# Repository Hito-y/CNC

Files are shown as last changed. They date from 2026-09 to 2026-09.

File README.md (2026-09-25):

# 自作CNC フレーム (PrintNC V4 ベース / 3Dプリンター不要版)

[PrintNC](https://wiki.printnc.info/en/home) V4 の構成 (75x50x3 角パイプ + HGR20 レール + 1610 ボールねじ) をベースに、
**3Dプリント部品を使わず、角パイプ・平板・山形鋼の切断と穴あけだけで作れる**ように簡易化したフレームの
パラメトリック 3D モデル (Python / CadQuery) です。

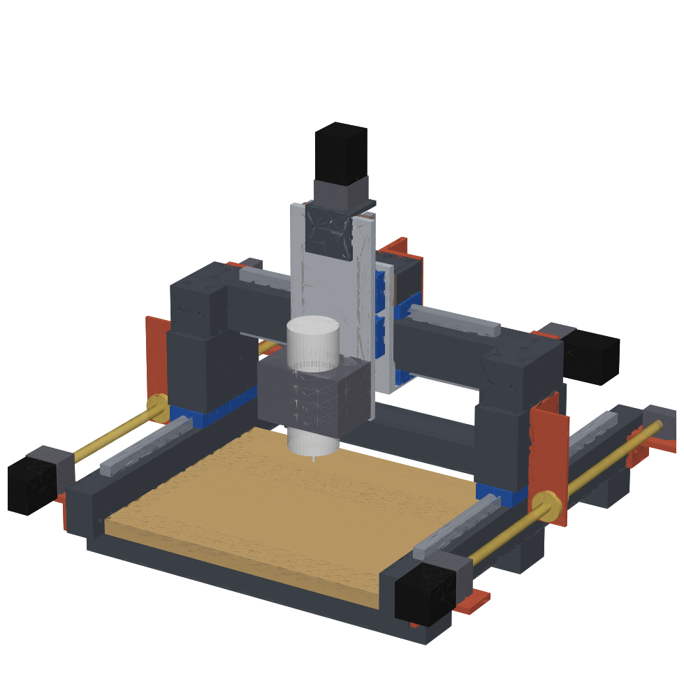
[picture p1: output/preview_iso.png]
preview


## 元モデルについて

- PrintNC V4 の公式 Fusion 360 モデル (V4.0.30 Metalcutter / Woodcutter) は **Discord でのみ配布** されていて、
  この環境からはダウンロードできませんでした ([Files ページ](https://wiki.printnc.info/en/v4/files))。
- 代わりに、公開されている V4 の BOM 生成スクリプト
  [interias/PrintNC-BOM-Generator](https://github.com/interias/PrintNC-BOM-Generator) の部品定義
  (Y Frame / X Frame / Y Roller / Y Roller Brace / X Gantry / X Roller / 1Z Plate / 全ネジ締結 など) を参考に、
  構成を Python で組み直しています。**寸法は V4 公式モデルと一致しません。**
- 公式 `.f3d` を Discord から入手したら、STEP で書き出してこのリポジトリに置けば、寸法の照合と修正ができます。
- PrintNC は CC BY 4.0 です。

## 3Dプリント部品の置き換え

| V4 の部品 | この版での置き換え |
|---|---|
| ローラープレート (15mm 3Dプリント) | 12mm アルミ板 (V4 でも切削版として指定されている厚み) |
| ボールねじナットマウント (印刷/切削) | 山形鋼に Φ29 の穴を開けてナットを直接固定 |
| Z 軸まわりの印刷部品 | 12mm アルミ Z プレート、Z レール下のスペーサー (平鋼 20x10)、HM10-57 取付用の山形鋼 |
| BK/BF/HM の台座 | 平鋼スペーサー / 山形鋼 |
| 印刷ドリルガイド・組立治具 | 自動生成する **穴位置表 (CSV)** と **1:1 型紙 (SVG)**。組立時の直角は対角線を測って出す |
| フレーム接合 | 溶接なし。M8 ボルト + リベットナット、M6 皿ボルトで締結 |

## 公式 .f3d を STEP に変換する (Fusion スクリプト)

`.f3d` は Autodesk Fusion 専用の形式で、Fusion の外では読めない。
[`tools/F3dToStep`](tools/F3dToStep/F3dToStep.py) は Fusion の中で動かす Python スクリプトで、次のことを行う。

- 選んだ `.f3d` (複数可) を順に開いて `<名前>.step` を書き出す
- ユーザーパラメータの一覧を `<名前>_params.csv` に書き出す
- スクリプト先頭の `PARAM_OVERRIDES` に書いた値 (例: `XCuttingArea`) に変えてから書き出す。元の `.f3d` は変更しない

実行方法: Fusion → ユーティリティ → アドイン → スクリプトとアドイン → スクリプトの「+」で `tools/F3dToStep` フォルダを追加 → 実行。

### Fusion を使わない方法 (Autodesk のクラウド変換)

[`tools/f3d_to_step_aps.py`](tools/f3d_to_step_aps.py) は Autodesk Platform Services (APS) の Model Derivative API に
`.f3d` をアップロードして STEP を受け取る。APS のアカウントと Client ID / Secret が必要 (Fusion のインストールは不要)。

```bash
export APS_CLIENT_ID=... APS_CLIENT_SECRET=...
python tools/f3d_to_step_aps.py --list-formats        # f3d から変換できる形式を確認
python tools/f3d_to_step_aps.py PrintNC_V4.f3d         # -> PrintNC_V4.step
```

## 使い方

```bash
pip install -r requirements.txt
python build.py                                  # 既定: 加工範囲 300 x 400 x 150
python build.py --cut_z 100 --out output_z100       # 別の寸法で試す (output/ は上書きしない)
python build.py --pos_x 0 --pos_y 0 --pos_z 0    # 可動部を端に寄せた姿勢で出力 (干渉確認用)
python build.py --no-step --no-render            # 表と図面だけ素早く更新
```

パラメータはすべて [`printnc_simple/params.py`](printnc_simple/params.py) にあり、`--<名前> 値` で上書きできます。
加工範囲を変えると、レール長・ガントリー長・支柱高さ・Z ストローク・穴位置がまとめて再計算されます。

## 出力 (`output/`)

| ファイル | 内容 |
|---|---|
| `printnc_simple.step` | アセンブリ (部品ごとに色付き)。Fusion 360 / FreeCAD に読み込んで続きの設計に使う |
| `printnc_simple.stl` | 全体の STL (GitHub 上で 3D プレビューできる) |
| `summary.md` | 主要寸法、自動チェックの結果、切断リスト、購入品リスト |
| `cut_list.csv` | 切断リスト (Excel で開ける) |
| `drill_holes.csv` | 全加工品の穴位置 (面・端からの距離・穴径・用途) |
| `drawings/*.svg` | 面ごとの穴あけ図。380mm 以下の面は **1:1 型紙** (100% で印刷してポンチ打ち) |
| `preview.png` / `preview_iso.png` | 4 面図 / アイソメ図 |

座標系: X = ガントリー方向 (左右)、Y = 前後 (−Y が手前)、Z = 上。原点は床面上のフレーム中心。

## 加工範囲

**300 (X) × 400 (Y) × 150 (Z)** で確定。400 × 300 案 (ガントリー長 750mm) と比べて、ガントリーが 650mm と短く、
たわみは長さの 3 乗に比例するので約 2/3 になる。剛性を優先してこちらを採用した。

## 構成 (V4 パラメータ準拠)

[`reference/printnc_v4_user_parameters.csv`](reference/printnc_v4_user_parameters.csv) (V4 の Fusion ユーザーパラメータ) に合わせています。

- ベース: X フレーム 3 本 (75x50x3 を寝かせた足) の上に Y フレーム 2 本 (75x50x3 を立てる) を載せ、
  M8 ボルトとリベットナットで縦に締結。前後の X フレームは端から 50mm 内側
- Y 軸: HGR20 を Y フレーム上面に固定、1 本に HGW20CC ×2。Y ローラーは幅 75、長さ 150
- ガントリー: 75x75x4 を 1 本、Y ローラーに直接載せる (支柱なし)。ローラー中心から 25mm 後ろにずらし、
  前に空いた部分にガントリーブレース (75x50x6) を置いて留める
- X 軸: ガントリーの **上面と下面** に HGR20。上はトップローラー (75x50x3)、下はボトムローラー (アルミ山形 100x50x6)。
  両者の前面にシム 8mm を介してローラープレート (アルミ 12mm) を付ける
- Z 軸: 2Z 構成 (HGR15 ×2、HGH15CA ×4)。キャリッジをローラープレートに固定し、レール側 (Z プレート) が上下する
- スピンドルクランプの穴は 125 × 64 (V4 の標準 80mm クランプ)

### Z 150mm のための変更

V4 標準の Y ローラー高さ 50 では、捨て板からガントリー下までが約 94mm しかない。
PrintNC の FAQ にある「ローラーを背の高い角パイプにする」方法で対応し、`cut_z` から高さを自動で選ぶ。

| cut_z | Y ローラー | 捨て板からガントリー下まで |
|---|---|---|
| 60 | 75x50 (V4 標準) | 94 |
| 100 | 75x75 | 119 |
| 150 (既定) | 125x75 | 169 |

ローラーが高くなるほどガントリーも高くなり、剛性面では不利になる。

## 自動チェック

- `build.py` を実行するたびに、穴の縁からの距離と穴同士の間の肉厚が 3mm 以上あるかを確認する (座ぐりの径も含む)
- `python tools/check_clash.py` で、可動部を中央と両端に置いたときに部品同士が干渉しないかを確認できる

## 未確定・要確認

- **X / Y ボールねじの位置は V4 パラメータに情報がなく、仮置き** (図の赤茶色の部品)。
  Y はフレームの外側、X はガントリーの後ろに置いている。公式 STEP で確認して直す
- 上下 X レールの取付面 (上面と下面) はパラメータ名と wiki の記述からの推定
- 購入品 (HM12-57、BK/BF、ナットブロック) の穴位置は代表値。「現物合わせ」の穴は部品が届いてから寸法を測って決める
- ケーブルチェーン、リミットセンサー、配線は含めていない
- ガントリーのたわみなど、剛性の計算はしていない

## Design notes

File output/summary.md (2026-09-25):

# 簡易 PrintNC フレーム 設計サマリー

`python build.py` で自動生成。寸法は mm。

## 主要寸法

| 項目 | 値 |
|---|---|
| 加工範囲 X × Y × Z | 300 × 400 × 150 |
| フレーム外形 X × Y (Yねじ・モーター除く) | 615 × 740 |
| 全幅 (Yねじ含む, 目安) | 800 |
| ガントリー上面 / トップローラー上面の高さ | 355 / 435 |
| 左右Yフレーム中心間 | 565 |
| ガントリー (75x75x4) 長さ | 640 |
| X / Y レール長 | 465 / 600 |
| Yローラー高さ (自動選択) | 125 |
| 捨て板上面からガントリー下 (最下点) まで | 169 |
| Zストローク | 165 |
| 工具先端の到達範囲 (捨て板上面基準) | -5 〜 160 |
| 主軸の Yローラー中心からの前方オフセット | 132.5 |
| 捨て板 X × Y | 511 × 420 |

## 自動チェック

- 穴の縁距離・穴間の肉厚: すべて 3mm 以上

赤茶色の部品 (Xねじ/Yねじまわり) は V4 パラメータに情報がない仮置き。

## 加工品 (切断リスト)

| 部品 | 素材 | 切断長 | 外形 | 数量 | 備考 |
|---|---|---|---|---|---|
| X Frame Tubing | 角パイプ 75x50x3 | 615 | 615 x 75 x 50 | 3 | 75面を下に寝かせて足にする。Yフレームを上に載せて M8 で縦に締結 |
| Y Frame Tubing | 角パイプ 75x50x3 | 740 | 740 x 75 x 50 | 2 |  |
| Y Roller Tubing | 角パイプ 125x75x3 | 150 | 150 x 125 x 75 | 2 | 幅 75 を横、高さ 125。先にキャリッジを留めてからガントリーを載せる |
| X Gantry Tubing | 角パイプ 75x75x4 | 640 | 640 x 75 x 75 | 1 | Yローラーに直接載せ、ローラー中心から 25 後ろへずらす |
| Gantry Brace | 角パイプ 75x50x6 | 75 | 75 x 75 x 50 | 2 | ガントリー前面と Yローラー上面をつなぐ [V4: GantryBrace] |
| X Top Roller (X Roller Tubing) | 角パイプ 75x50x3 | 150 | 150 x 75 x 50 | 1 | 上Xキャリッジに載せる |
| X Roller Shim | 平鋼/アルミ t=8 |  | 150 x 50 x 8 | 1 |  |
| X Bottom Roller (X Roller Angle) | アルミ山形 L100x50x6 | 150 | 150 x 100 x 50 | 1 | 下Xキャリッジの下に付け、立ち上がりをローラープレートに留める |
| Roller Plate | アルミ板 t=12 |  | 210 x 150 x 12 | 1 | V4 の RollerPlate (切削版 12mm)。3Dプリント版の代替 |
| X Nut Bracket (angle) | 山形鋼 L75x70x10 (仮置き) | 147.5 | 147.5 x 75 x 70 | 1 | トップローラー背面に 3mm スペーサーを挟んで共締め。Xねじ位置は V4 未確認 |
| X Nut Spacer | 平鋼 t=3 (仮置き) |  | 75 x 50 x 3 | 1 |  |
| Mount Spacer Plate | 平鋼 t=18 (仮置き) |  | 70 x 45 x 18 | 2 |  |
| Y Nut Bracket (angle) | 山形鋼 L65x80x6 (仮置き) | 180 | 180 x 80 x 65 | 2 | Yローラー外側面に共締め。Yねじ位置は V4 未確認 |
| Y Mount Angle | 山形鋼 L100x65x10 (仮置き) | 60 | 100 x 60 x 55 | 4 | Yフレーム外側面に M8 で固定し、上に BK/BF/HM を載せる |
| Z Plate (2Z) | アルミ板 t=12 |  | 325 x 145 x 12 | 1 | HGR15 x2 をスペーサー経由で背面に固定 (レール可動) |
| Z Rail Spacer (flat bar) | 平鋼 20x10 | 325 | 325 x 20 x 10 | 2 | ナットブロックの逃げ代を作る |
| Z Top Angle | 山形鋼 L75x75x8 | 80 | 80 x 75 x 75 | 1 | HM10-57 を載せる |

## 購入品

| 部品 | 型番/仕様 | 数量 |
|---|---|---|
| HGR20 Rail (Y) | HGR20 L=600 | 2 |
| HGW20CC Carriage | HGW20CC | 8 |
| HGR20 Rail (X) | HGR20 L=465 | 2 |
| SFU1610 Nut | SFU1610 | 3 |
| HM12-57 | HM12-57 | 3 |
| NEMA23 Motor | NEMA23 57x57x76 | 4 |
| BF12 | BF12 | 3 |
| SFU1610 Ballscrew (X) | SFU1610 L≈620 | 1 |
| SFU1610 Ballscrew (Y) | SFU1610 L≈730 | 2 |
| Wasteboard | 合板/MDF t=25 | 1 |
| HGH15CA Carriage | HGH15CA | 4 |
| HGR15 Rail (Z) | HGR15 L=325 | 2 |
| HM10-57 | HM10-57 | 1 |
| SFU1204 Ballscrew (Z) | SFU1204 L≈305 | 1 |
| SFU1204 Nut + Block | SFU1204 + ナットブロック | 1 |
| 80mm Spindle Clamp | 80mm クランプ | 1 |
| Spindle 80mm | Φ80 スピンドル | 1 |

角パイプ合計長さ: 約 4565 mm (切り代・端材別)

## 穴あけ図 (drawings/)

1:1 と書かれたものは 100% で印刷してポンチ打ちの型紙として使える。100mm スケールバーで倍率を確認すること。

- [X_Frame_Tube_1_zp_wall.svg](drawings/X_Frame_Tube_1_zp_wall.svg)
- [X_Frame_Tube_1_zm_wall.svg](drawings/X_Frame_Tube_1_zm_wall.svg)
- [X_Frame_Tube_2_zp_wall.svg](drawings/X_Frame_Tube_2_zp_wall.svg)
- [X_Frame_Tube_2_zm_wall.svg](drawings/X_Frame_Tube_2_zm_wall.svg)
- [X_Frame_Tube_3_zp_wall.svg](drawings/X_Frame_Tube_3_zp_wall.svg)
- [X_Frame_Tube_3_zm_wall.svg](drawings/X_Frame_Tube_3_zm_wall.svg)
- [Y_Frame_Tube_L_zp_wall.svg](drawings/Y_Frame_Tube_L_zp_wall.svg)
- [Y_Frame_Tube_L_xm.svg](drawings/Y_Frame_Tube_L_xm.svg)
- [Y_Frame_Tube_L_zm_wall.svg](drawings/Y_Frame_Tube_L_zm_wall.svg)
- [Y_Roller_L_zp_wall.svg](drawings/Y_Roller_L_zp_wall.svg)
- [Y_Roller_L_xm.svg](drawings/Y_Roller_L_xm.svg)
- [Y_Roller_L_zm_wall.svg](drawings/Y_Roller_L_zm_wall.svg)
- [Y_Frame_Tube_R_xp.svg](drawings/Y_Frame_Tube_R_xp.svg)
- [Y_Frame_Tube_R_zp_wall.svg](drawings/Y_Frame_Tube_R_zp_wall.svg)
- [Y_Frame_Tube_R_zm_wall.svg](drawings/Y_Frame_Tube_R_zm_wall.svg)
- [Y_Roller_R_xp.svg](drawings/Y_Roller_R_xp.svg)
- [Y_Roller_R_zp_wall.svg](drawings/Y_Roller_R_zp_wall.svg)
- [Y_Roller_R_zm_wall.svg](drawings/Y_Roller_R_zm_wall.svg)
- [X_Gantry_Tube_yp_wall.svg](drawings/X_Gantry_Tube_yp_wall.svg)
- [X_Gantry_Tube_zp_wall.svg](drawings/X_Gantry_Tube_zp_wall.svg)
- [X_Gantry_Tube_zp.svg](drawings/X_Gantry_Tube_zp.svg)
- [X_Gantry_Tube_ym_wall.svg](drawings/X_Gantry_Tube_ym_wall.svg)
- [X_Gantry_Tube_zm_wall.svg](drawings/X_Gantry_Tube_zm_wall.svg)
- [Gantry_Brace_L_zp.svg](drawings/Gantry_Brace_L_zp.svg)
- [Gantry_Brace_L_ym.svg](drawings/Gantry_Brace_L_ym.svg)
- [Gantry_Brace_R_zp.svg](drawings/Gantry_Brace_R_zp.svg)
- [Gantry_Brace_R_ym.svg](drawings/Gantry_Brace_R_ym.svg)
- [X_Top_Roller_zp_wall.svg](drawings/X_Top_Roller_zp_wall.svg)
- [X_Top_Roller_ym.svg](drawings/X_Top_Roller_ym.svg)
- [X_Top_Roller_zm_wall.svg](drawings/X_Top_Roller_zm_wall.svg)
- [X_Roller_Shim_ym.svg](drawings/X_Roller_Shim_ym.svg)
- [X_Bottom_Roller_ym.svg](drawings/X_Bottom_Roller_ym.svg)
- [X_Bottom_Roller_zm.svg](drawings/X_Bottom_Roller_zm.svg)
- [Roller_Plate_ym.svg](drawings/Roller_Plate_ym.svg)
- [X_Nut_Bracket_xm.svg](drawings/X_Nut_Bracket_xm.svg)
- [X_Nut_Bracket_ym.svg](drawings/X_Nut_Bracket_ym.svg)
- [X_Nut_Spacer_ym.svg](drawings/X_Nut_Spacer_ym.svg)
- [X_HM12-57_Spacer_yp.svg](drawings/X_HM12-57_Spacer_yp.svg)
- [X_BF12_Spacer_yp.svg](drawings/X_BF12_Spacer_yp.svg)
- [Y_Nut_Bracket_L_xm.svg](drawings/Y_Nut_Bracket_L_xm.svg)
- [Y_Nut_Bracket_L_ym.svg](drawings/Y_Nut_Bracket_L_ym.svg)
- [Y_HM12-57_Angle_L_zp.svg](drawings/Y_HM12-57_Angle_L_zp.svg)
- [Y_HM12-57_Angle_L_xm.svg](drawings/Y_HM12-57_Angle_L_xm.svg)
- [Y_BF12_Angle_L_zp.svg](drawings/Y_BF12_Angle_L_zp.svg)
- [Y_BF12_Angle_L_xm.svg](drawings/Y_BF12_Angle_L_xm.svg)
- [Y_Nut_Bracket_R_xp.svg](drawings/Y_Nut_Bracket_R_xp.svg)
- [Y_Nut_Bracket_R_ym.svg](drawings/Y_Nut_Bracket_R_ym.svg)
- [Y_HM12-57_Angle_R_xp.svg](drawings/Y_HM12-57_Angle_R_xp.svg)
- [Y_HM12-57_Angle_R_zp.svg](drawings/Y_HM12-57_Angle_R_zp.svg)
- [Y_BF12_Angle_R_xp.svg](drawings/Y_BF12_Angle_R_xp.svg)
- [Y_BF12_Angle_R_zp.svg](drawings/Y_BF12_Angle_R_zp.svg)
- [Z_Plate_ym.svg](drawings/Z_Plate_ym.svg)
- [Z_Rail_Spacer_ym.svg](drawings/Z_Rail_Spacer_ym.svg)
- [Z_Top_Angle_zp.svg](drawings/Z_Top_Angle_zp.svg)
- [Z_Top_Angle_ym.svg](drawings/Z_Top_Angle_ym.svg)

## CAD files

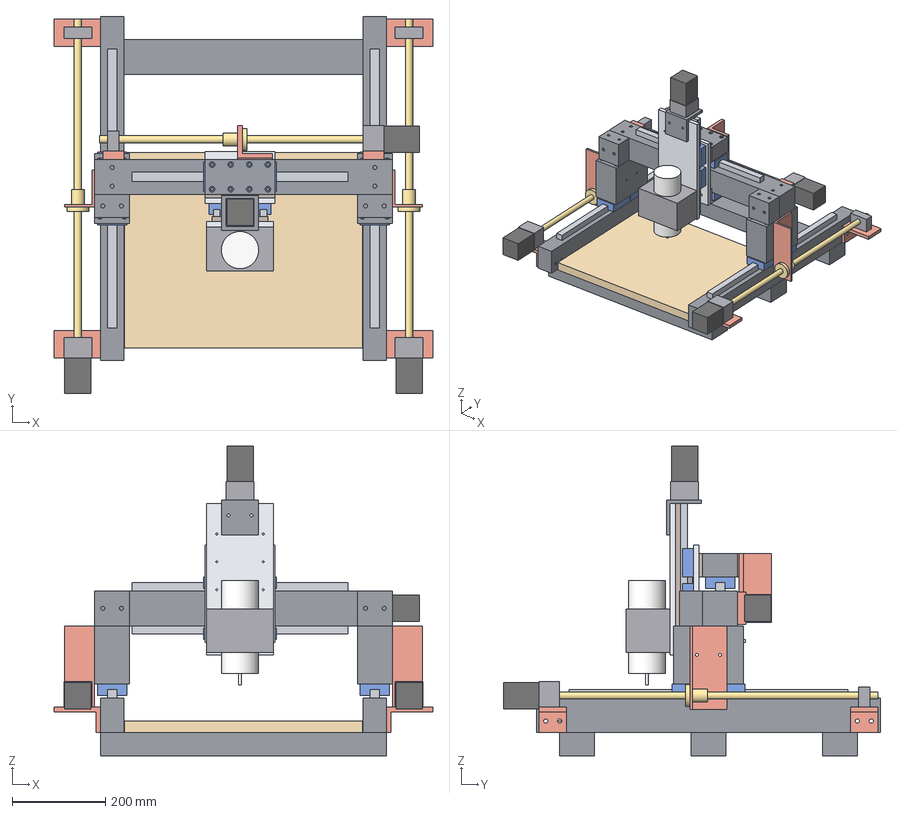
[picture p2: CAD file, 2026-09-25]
output/printnc_simple.step
815.0 x 811.0 x 666.5 mm
X_Frame_Tube_1
X_Frame_Tube_2
X_Frame_Tube_3
Y_Frame_Tube_L
Y_Rail_L
Y_Roller_L
Y_Carriage_L
Y_Carriage_L_n2
Y_Frame_Tube_R
Y_Rail_R
Y_Roller_R
Y_Carriage_R
Y_Carriage_R_n2
X_Gantry_Tube
X_Rail_Top
X_Rail_Bottom
Gantry_Brace_L
Gantry_Brace_R
X_Carriage
X_Carriage_n2
X_Carriage_n3
X_Carriage_n4
X_Top_Roller
X_Roller_Shim
X_Bottom_Roller
Roller_Plate
X_Nut_Bracket
X_Nut_Spacer
X_Nut
X_HM12-57_Spacer
HM12-57
NEMA23_Motor_X
X_BF12_Spacer
BF12
X_Ballscrew
Y_Nut_Bracket_L
Y_Nut_L
Y_HM12-57_Angle_L
HM12-57_n2
NEMA23_Motor_YL
Y_BF12_Angle_L
BF12_n2
Y_Ballscrew_L
Y_Nut_Bracket_R
Y_Nut_R
Y_HM12-57_Angle_R
HM12-57_n3
NEMA23_Motor_YR
Y_BF12_Angle_R
BF12_n3
Y_Ballscrew_R
Wasteboard
Z_Carriage
Z_Carriage_n2
Z_Carriage_n3
Z_Carriage_n4
Z_Plate
Z_Rail_Spacer
Z_Rail
Z_Rail_Spacer_n2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

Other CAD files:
output/printnc_simple.stl

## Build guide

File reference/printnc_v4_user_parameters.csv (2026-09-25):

FrameLong | mm | 75 mm | Base steel dimension for entire machine
FrameShort | mm | 50 mm | Base steel dimension for entire machine
FrameThick | mm | 3 mm | Base steel dimension for entire machine
FrameRadius | mm | 6 mm | Base steel dimension for entire machine
XFrameWidth | mm | FrameLong | XFrame specific dimension if different from base.
XFrameHeight | mm | FrameShort | XFrame specific dimension if different from base.
XFrameThick | mm | FrameThick | XFrame specific dimension if different from base.
XFrameRadius | mm | FrameRadius | XFrame specific dimension if different from base.
YFrameHeight | mm | FrameLong | YFrame specific dimension if different from base.
YFrameWidth | mm | FrameShort | YFrame specific dimension if different from base.
YFrameThick | mm | FrameThick | YFrame specific dimension if different from base.
YFrameRadius | mm | FrameRadius | YFrame specific dimension if different from base.
XCuttingArea | mm | 625 mm | Set to desired Xaxis cutting area.
YCuttingArea | mm | 625 mm | Set to desired Yaxis cutting area.
XGantryHeight | mm | 75 mm | XGantry specific dimension if different from base.
XGantryWidth | mm | 75 mm | XGantry specific dimension if different from base.
XGantryThick | mm | 4 mm | XGantry specific dimension if different from base.
XGantryRadius | mm | 10 mm | XGantry specific dimension if different from base.
YRollerHeight | mm | FrameShort | YRoller specific dimension if different from base.
YRollerWidth | mm | max(FrameLong;XFrameWidth) | YRoller specific dimension if different from base.
YRollerThick | mm | 3 mm | Use 3mm thickness steel for 75mm roller width to prevent radius to bolt head conflict
YRollerRadius | mm | FrameRadius | YRoller specific dimension if different from base.
YRollerLength | mm | 50 mm + ( YCarriageCount * 50 mm ) | YRoller specific dimension if different from base.
XGantryOffset | mm | 25 mm | Sets Gantry back from center of Y roller to allow addition of gusset bracket.
SRF |  | 25 | Steel Rounding Factor. Set to 5, 10, 25, or 50 as desired.
YCarriageCount |  | 2 | Number of Y Carriages per linear rail.
XCarriageCount |  | 2 | Number of X Carriages per linear rail.
XTopRollerHeight | mm | FrameShort | XTopRoller specific dimension if different from base.
XTopRollerWidth | mm | max(FrameLong;XGantryWidth) | XTopRoller specific dimension if different from base.
XTopRollerThick | mm | 3 mm | Use 3mm thickness steel for 75mm roller width to prevent radius to bolt head conflict
XTopRollerRadius | mm | FrameRadius | XTopRoller specific dimension if different from base.
XBottomRollerHeight | mm | 50 mm | XBottomRoller height
XBottomRollerWidth | mm | max(75 mm; 25 * ceil(( XTopRollerWidth + XRollerShimThick - 6 mm ) / 25)) | Edit to actual width of XBottomRoller to adjust for lower drill guide.
XBottomRollerThick | mm | 6 mm | XBottomRoller thickness
XBottomRollerRadius | mm | 6 mm | XBottomRoller radius. For 6061, measure using radius tool. For 6063, set to 0.
XRollerLength | mm | 50 mm + ( XCarriageCount * 50 mm ) | Calculated based on minimum distance between HGW20CC carriages. Can be manually set longer.
YCarriageB | mm | 53 mm | Affects the drill guides only: 53 for HGW20CC, 32 for HGH20CA
YCarriageC | mm | 40 mm | Affects the drill guides only: 40 for HGW20CC, 36 for HGH20CA
YCarriageHeight | mm | 30 mm | Future Parameter - not implemented
XCarriageB | mm | 53 mm | Affects the drill guides only: 53 for HGW20CC, 32 for HGH20CA
XCarriageC | mm | 40 mm | Affects the drill guides only: 40 for HGW20CC, 36 for HGH20CA
XCarriageHeight | mm | 30 mm | Future Parameter - not implemented
XRollerOffset | mm | 0 mm | Moves the XTopRoller towards the back of the CNC if using 50x100 for top roller
SpindleClampHoleHorizontal | mm | 125 mm | Spindle Clamp Hole spacing width: 108 for Narrow, 125 for Standard 80mm spindle clamp
SpindleClampHoleVertical | mm | 64 mm | Spindle Clamp Hole spacing height: 50 for Narrow, 64 for Standard 80mm spindle clamp
XGantryLength | mm | calcXFrameLength + ( YRollerWidth - YFrameWidth ) | Length of XGantry
XFrameFrontOffset | mm | 50 mm | Moves the front XFrame tubing back. Set this to 150 to move the first X frame steel back for vertical clamping
XFrameBackOffset | mm | 50 mm | Moves the rear XFrame tubing forward
RollerPlateThick | mm | 15 mm | 12mm for milled aluminum, 15mm for 3d printed
XRollerShimThick | mm | 8 mm | Adds shim between XTopRoller and ZPlate. Set 8mm to use 6mm angle and square tubing.
ZCarriageCount |  | 2 | Number of Z Carriages per linear rail. 1 uses HGW20CC, 2 uses HGH15CA
GantryBraceHeight | mm | 75 mm | Gantry to Yroller brace height
GantryBraceWidth | mm | 50 mm | Gantry to Yroller brace width
GantryBraceThick | mm | 6 mm | Gantry to Yroller brace thickness
GantryBraceRadius | mm | 6 mm | Gantry to Yroller brace radius
XRailtoYRollerLeftGap | mm | 5 mm | 25 for single Xcarriage, 5 for dual Xcarriage
XRailtoYRollerRightGap | mm | 20 mm | 25 for single Xcarriage, 20 for dual Xcarriage
KitEnable |  | 0 | 0 for DIY, 1 for Kit

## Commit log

2026-09-24 Add parametric PrintNC V4-based CNC frame without 3D printed parts
    CadQuery model of a simplified PrintNC V4 style frame (75x50x3 tube,
    HGR20 rails, 1610 ballscrews) where all printed parts are replaced by
    steel/aluminium plate and angle. build.py exports STEP/STL, cut list,
    drill hole table, 1:1 drilling templates (SVG) and preview renders, and
    checks hole edge distances.
    Claude-Session: https://claude.ai/code/session_01X8rwhVD4knzzBzcbddAU2D
    [cut_list.csv, drill_holes.csv, printnc_simple.step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]
2026-09-24 Set default work area to 300x400x150 and add 400x300 variant
    A shorter gantry (650 vs 750 mm) is stiffer, so 300 (X) x 400 (Y) is the
    new default. The 400x300 layout is generated into output_400x300/ for
    comparison.
    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
    [cut_list.csv, drill_holes.csv, printnc_simple.step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]
2026-09-24 Settle on 300x400x150 work area and drop 400x300 variant
    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
    [cut_list.csv, drill_holes.csv, printnc_simple.step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]
2026-09-25 Add APS-based f3d to STEP converter that does not need Fusion
    Uploads the .f3d to a transient APS bucket, runs a Model Derivative
    translation job and downloads the STEP (or IGES/STL/OBJ) derivative.
    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
2026-09-25 Add PrintNC V4 Fusion user parameter list for reference
    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
    [printnc_v4_user_parameters.csv]
2026-09-25 Rebuild frame to follow PrintNC V4 user parameters
    - X frame tubes laid flat as feet with Y frame tubes on top (M8 + rivet nuts)
    - 75x75x4 gantry sitting directly on 150mm Y rollers, offset 25mm back,
    with 75x50x6 gantry braces
    - X rails on gantry top and bottom with top roller tube, bottom roller
    angle, 8mm shim and 12mm roller plate
    - Y roller height chosen from cut_z (125x75 for 150mm Z)
    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
    [cut_list.csv, drill_holes.csv, printnc_simple.step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]
